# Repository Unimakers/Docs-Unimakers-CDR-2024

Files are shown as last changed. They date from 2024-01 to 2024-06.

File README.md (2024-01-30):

# Template-project

Template pour la création d'un repo type projet pour le MakerSpace. Doc gérée via le thème [Just-The-Docs](https://just-the-docs.com) en vanilla.

## Bienvenue sur Notre Projet

Ce repository est le cœur de notre projet. Ici, vous trouverez toutes les ressources nécessaires pour comprendre, utiliser et contribuer à notre projet.

### Contenu du Repository

- **Documentation :** Toutes les documentations techniques et guides d'utilisation sont disponibles dans le dossier `docs`. Voir le site de doc associé. 
- **project :** Toutes les sources de notre projet.

### Comment Utiliser ce Repository ?

- Pour commencer, consultez la documentation dans le dossier `docs`.
- Si vous souhaitez contribuer au projet, veuillez lire nos directives de contribution.

## Contribution

Nous accueillons et apprécions toute contribution. Si vous souhaitez contribuer, veuillez consulter notre guide de contribution pour connaître nos attentes et notre processus.

## Contact

Si vous avez des questions ou des suggestions, n'hésitez pas à nous contacter.

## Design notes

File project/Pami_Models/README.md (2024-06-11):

Voici le lien vers le fichier final du projet :

https://cad.onshape.com/documents/02834f8063c7122651a1e116/w/560aea271cad3373c1abc5b6/e/3381d3059c6bdee013f704c1

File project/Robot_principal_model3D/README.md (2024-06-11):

# Lien OnShape du robot principal

https://cad.onshape.com/documents/e7f1cd6065f4855bbf7ee889/w/294a25ebd50bad2a9f131b9e/e/20f33280a5619a7927049fd3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

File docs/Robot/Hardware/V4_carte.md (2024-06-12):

---
layout: technicals
grand_parent: Robot
parent: Hardware
nav_order: 4
title: V4 Carte
---

# Le temps est écoulé, le 4e candidat est retenu

<kicanvas-embed controls="full">
    <kicanvas-source src="./V4_carte_files/MainBoardV4.kicad_sch"></kicanvas-source>
    <kicanvas-source src="./V4_carte_files/Meca.kicad_sch"></kicanvas-source>
    <kicanvas-source src="./V4_carte_files/Power.kicad_sch"></kicanvas-source>
    <kicanvas-source src="./V4_carte_files/Servo.kicad_sch"></kicanvas-source>
    <kicanvas-source src="./V4_carte_files/Logic.kicad_sch"></kicanvas-source>
    <kicanvas-source src="./V4_carte_files/steppers.kicad_sch"></kicanvas-source>
    <kicanvas-source src="./V4_carte_files/MainBoardV4.kicad_pcb"></kicanvas-source>
</kicanvas-embed>

Voici la dernière carte à jour qui a participé à la coupe dans le robot. Cette carte nous a permis d'avoir tout ce dont nous avions besoin pour que le robot fonctionne correctement. Par rapport à la V3, cette carte a tous ses composants d'un seul côté du PCB, ce qui nous permettait de router tous les fils d'un côté du robot, minimisant les risques que les actionneurs s'emmêlent dans les fils.

Voici un schéma résumant les fonctionnalités de la carte !

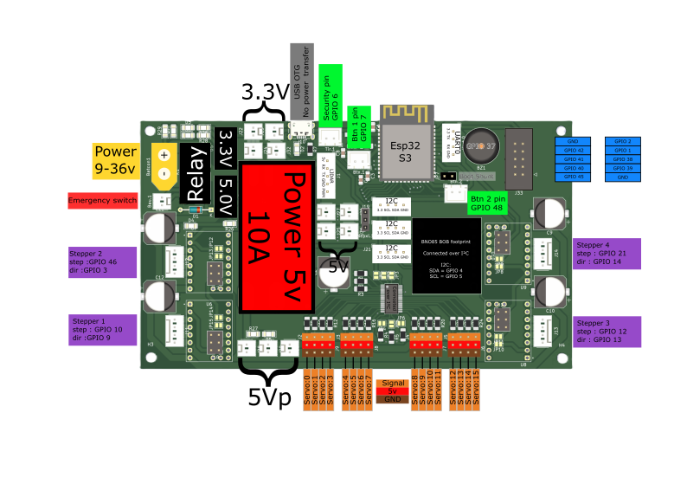
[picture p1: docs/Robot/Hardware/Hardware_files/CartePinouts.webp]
Pinout de la carte électronique


Quelques caractéristiques de cette carte :

| **Éléments** | **Détail** |
| --- | --- |
| Tension d'alimentation | Min : voir Traco puissance, Max : 36V |
| Type de microcontrôleur  | ESP32-S3-WROOM-1-8MB |
| Type de contrôleur Servo | PCA9685PW, connecté en I²C |
| Emplacements Servo | 16x, supportant jusqu'à 10A partagés |
| Type de driver | Par défaut : TMC2209, configurable en DRV8825 ou A4988 |
| Configuration drivers | TMC2209 : pas de configuration nécessaire, DRV8825/A4988 : souder les jumpers |
| Type de relais | Relay_SPST_TE_PCH-1xxx2M, ou à shunter en cas d'absence |
| Configuration relais | Choisir le relais en fonction de la tension utilisée. Sinon, shunter les connexions entre la COM et NO ! Ne pas utiliser le BAU sur carte si shunté ! |
| Type de gyroscope | BNO_085 en I²C |
| Tension de sortie 3,3V | Jusqu'à 2 ampères, partagés avec l'ESP32, les drivers et l'I²C |
| Tension de sortie 5V | Jusqu'à 2 ampères, partagés avec le LIDAR et Neopixel |
| Connecteurs I²C | 3,3V, partagés avec l'ESP32 |
| Connecteur Lidar | 5V, partagés avec Neopixel, UART 1, PWM |
| Connecteur Nappe | Compatible avec les cartes AREA |

> je laisse un peu de santé physique [ici](https://www.youtube.com/watch?v=dQw4w9WgXcQ) -Dylan

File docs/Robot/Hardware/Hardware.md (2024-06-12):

---
layout: technicals
parent: Robot
nav_order: 2
title: Hardware
has_children: true
---
## Sans éléments, on n'ira pas loin

Les robots comportent plusieurs systèmes de nature différente. Pour notre robot, nous avons identifié les systèmes suivants :

- Systèmes mécaniques
- Systèmes électroniques
- Systèmes lumineux

Chacun de ces systèmes joue un rôle distinct dans le fonctionnement du robot, mais ils ne fonctionnent pas indépendamment. Ils sont soigneusement interfacés pour que chaque composant contribue efficacement à l'ensemble du robot.

## Le mouvement, on y va de "pas en pas"

Pour le mouvement, nous avons opté pour des moteurs pas à pas Nema 17, couramment utilisés dans les imprimantes 3D et connus pour leur couple adéquat pour des systèmes légers.

<model-viewer disable-zoom src="./Hardware_files/Nema17.glb" ar ar-modes="webxr scene-viewer quick-look" camera-controls tone-mapping="commerce" poster="./Hardware_files/poster.webp" shadow-intensity="1"> </model-viewer>

Voici la [documentation](https://www.omc-stepperonline.com/fr/nema-17-bipolaire-45ncm-64oz-in-2a-42x42x40mm-4-fils-avec-1m-de-cable-et-connecteur-17hs16-2004s1) du Nema 17 utilisée.

<embed src="./Hardware_files/17HS16-2004S1.pdf" type="application/pdf" style="width: 100%; height: 100vh; border: none; display: block; margin: 0; padding: 0;"/>

Nous avons choisi ce modèle de moteur en utilisant le calculateur disponible sur le site du makerspace, en fonction du cahier des charges prévisionnel suivant :

[Calculateur en ligne](https://makerspace-amiens.fr/pages/calculateur-moteur-robot/){: .btn .btn-purple }

| Caractéristique | Valeur |
|---|---|
| Poids | 6 kg |
| Vitesse | 0,5 m/s|
| Accélération | 2 m/s² |
| Nombre de moteurs | 2 |
| Rayon roue motrice | 60 mm  |
| Tension d'alimentation  | 12 V |
| Efficacité | 65% |
| Temps de fonctionnement | 2 h |

Cependant, nous avons constaté que ces moteurs ne fournissaient pas le couple attendu en pratique, probablement en raison de la qualité des marques noname que nous avions. Cela nous a conduits à choisir un modèle supérieur, les Nema 23. Voici la [documentation](https://www.omc-stepperonline.com/fr/nema-23-bipolaire-1-8deg-0-9-nm-127-5oz-in-2a-3-6v-57x57x52mm-4-fils-23hs20-2004s).

<embed src="./Hardware_files/23HS20-2004S.pdf" type="application/pdf" width="100%" height="560px" />

Ces moteurs sont un peu plus encombrants que les Nema 17, mais ils permettent d'utiliser le robot en transmission directe (direct drive), c'est-à-dire que la roue est directement fixée sur l'arbre moteur.

<model-viewer src="./Hardware_files/NEMA23.gltf" ar ar-modes="webxr scene-viewer quick-look" camera-controls tone-mapping="commerce" poster="./Hardware_files/Nemaposter.webp" shadow-intensity="1" disable-zoom>
    <div class="progress-bar hide" slot="progress-bar">
        
    </div>
</model-viewer>

Un moteur pas à pas fonctionne en effectuant des rotations par pas. Un changement de polarité permet de passer d'une position à une autre. Dans notre cas, ce changement est géré par notre programme via un driver nommé TMC2209. La [documentation du TMC2209 ici](https://www.analog.com/en/products/TMC2209.html).

<embed src="./Hardware_files/TMC2209_datasheet_rev1.08.pdf" type="application/pdf" width="100%" height="600px" />

Pour les mouvements des actionneurs, nous avons principalement utilisé des servomoteurs. Ce sont des moteurs à courant continu (DC) qui intègrent un régulateur de position. En envoyant un signal PWM (pulse width modulation), en français MLI (modulation de largeur d'impulsion), nous pouvons commander le moteur à se positionner à un certain angle. 
Les références que nous avons utilisées sur le robot sont :
- FS 5115M [documentation ici](https://www.gotronic.fr/pj2-fs5115m-2553.pdf)
- Servo MG996R [documentation ici](./Hardware_files/mg996r.pdf)

<model-viewer src="./Hardware_files/MG996RServo.glb" ar ar-modes="webxr scene-viewer quick-look" camera-controls tone-mapping="commerce" poster="./Hardware_files/posterServo.webp" shadow-intensity="1">
    <div class="progress-bar hide" slot="progress-bar">
        
    </div>
</model-viewer>

## Une source d'énergie, et ce n'est pas de la vapeur !

Comme source d'énergie, nous avons opté pour des batteries déjà disponibles dans l'association, notamment les Parkside A3.

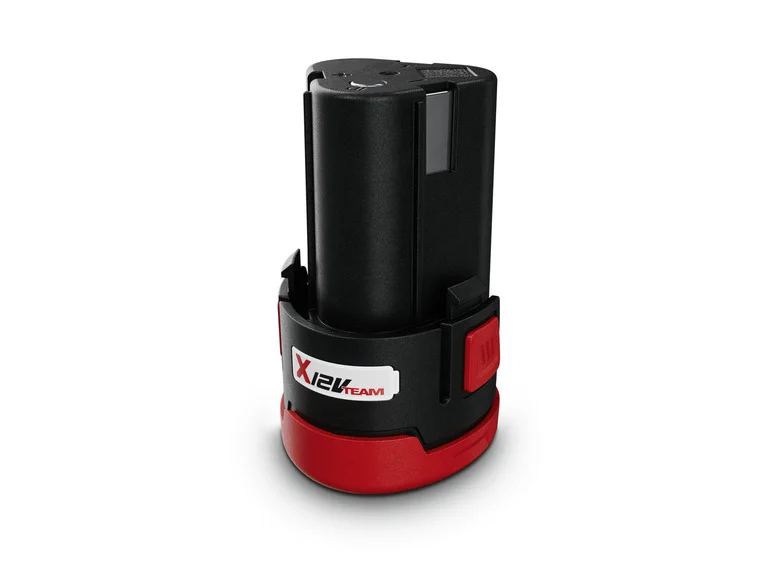
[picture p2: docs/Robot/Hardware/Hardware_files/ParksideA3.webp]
Batterie Parkside


Deux de ces batteries sont en série dans le robot pour augmenter la tension vers 24V, ce qui permet de suivre les courbes de couple proposées par les Nema 23.

Pour l'autonomie de ces batteries, nous sommes aux alentours de 1h30 voire 2h.

Nous avons pensée a prendre des parkside B3, mais ceux si etaient trop encombrant, ainsi qu'une tension non adapté au besoins

## Des yeux, il en faut pour ne pas etre aveugle

Nous avons opté pour un LIDAR RP A2 de slamtec, ce LIDAR est a déja disponible dans l'association

Voici la page du lidar pour plus d'information [Page du lidar](https://www.slamtec.ai/product/slamtec-rplidar-a2/)

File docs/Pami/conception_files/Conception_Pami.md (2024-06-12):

---
layout: technicals
parent: PAMI
nav_order: 1
title: Conception
has_children: true
---

# Conception & Modélisation des PAMI

## Introduction

Les **PAMI** (Petit Actionneur Mobile Indépendant) sont de petits robots soumis à plusieurs règles de conception, dont les contraintes volumétriques sont les plus importantes. En effet, il n'y a pas de nombre limite de PAMI présents sur la table de jeu, cependant, l'ensemble des PAMI doit tenir dans une zone de 150mm x 450mm et 150mm de hauteur. Ils ont également une limite de poids fixée à 1,5kg dans le règlement final. Cependant, le premier règlement (béta) limitait le poids des PAMI à 1kg. Afin de respecter les contraintes volumétriques, la conception de base repose sur un volume carré ou rectangulaire dans lequel nous intégrons nos composants.

### PoC (Proof of Concept)

Avant toute conception des PAMI, il était crucial de choisir le moteur adéquat pour concevoir le corps du robot. Pour cela, j'ai utilisé un outil de calcul de couple. Avec ces informations en main, j'ai trouvé les moteurs steppers nécessaires : des [Nema 14 rond](https://www.omc-stepperonline.com/fr/rond-nema-14-bipolaire-0-9deg-9-ncm-12-75-oz-in-1-0a-36-5x17-5mm-4-fils-14hr07-1004vrn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) ou pancake.

Suite à ce choix, j'ai rapidement réalisé une petite pièce pour valider les moteurs et commencer à imaginer les volumes du PAMI.

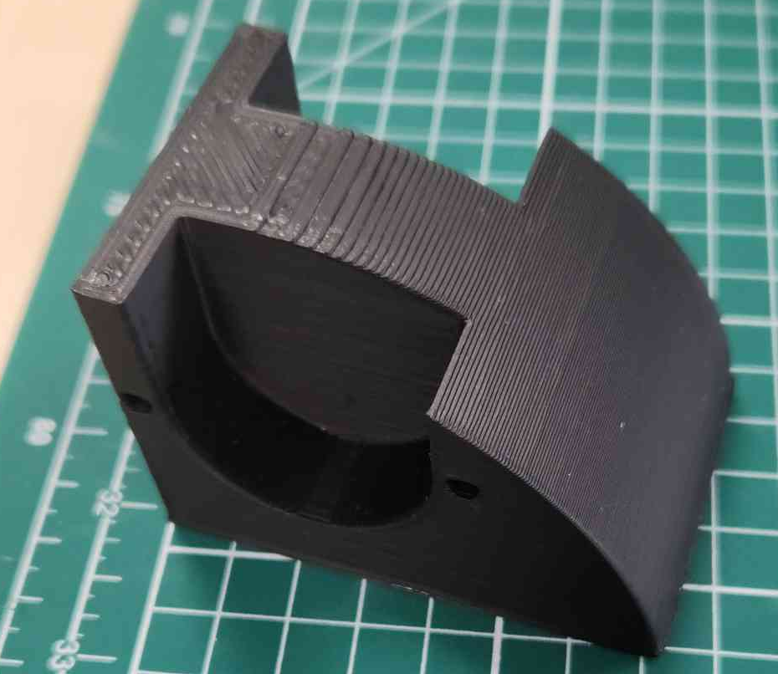
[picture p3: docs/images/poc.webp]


La première version de la conception des PAMI visait à créer un maximum de PAMI dans une zone la plus compacte possible. Après plusieurs heures de conception, j'ai obtenu un premier modèle 3D.

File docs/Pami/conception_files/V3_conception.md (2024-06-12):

---
layout: technicals
grand_parent: PAMI
parent: Conception
nav_order: 3
title: Version Final
---

<style>
	.video-container {
		position: relative;
		padding-bottom: 56.25%; /* Ratio 16:9 */
		height: 0;
		overflow: hidden;
		max-width: 100%;
		background: #000;
	}

	.video-container video {
		position: absolute;
		top: 0;
		left: 0;
		width: 100%;
		height: 100%;
	}
    .belleimage:hover {
        transform: scale(1.35);
    }
</style>

# Conception & Modélisation des PAMI

## Version Finale

<model-viewer src="./3d_files/pami-vfinal.glb" ar ar-modes="webxr scene-viewer quick-look" camera-controls tone-mapping="neutral" poster="./3d_files/v3.webp" shadow-intensity="1" style="display: block; margin-left: auto; margin-right: auto; height: 600px; width: 600px;">
    <div class="progress-bar hide" slot="progress-bar">
        
    </div>
</model-viewer>

La version 3, ou version finale, est une continuité et une amélioration du concept de la V2. Le changement principal est le remplacement des steppers par une nouvelle référence. La grande modification est le changement complet de l'emplacement des composants, passant d'un agencement circulaire à un agencement carré.

Avec le body réadapté et la carte finale réalisée, nous avons pu continuer notre conception. Sur la plaque supérieure, il fallait intégrer plusieurs emplacements pour les différents composants qui s'y fixent :

- Un emplacement pour visser le bouton d'arrêt d'urgence
- Un support pour le capteur Reed
- Un emplacement pour le switch de stratégie (bleu ou jaune)
- Un support et une attache pour le capteur ultrason
- Un emplacement pour le servo-moteur destiné à toucher les plantes

<div style="display: flex; justify-content: space-around;">
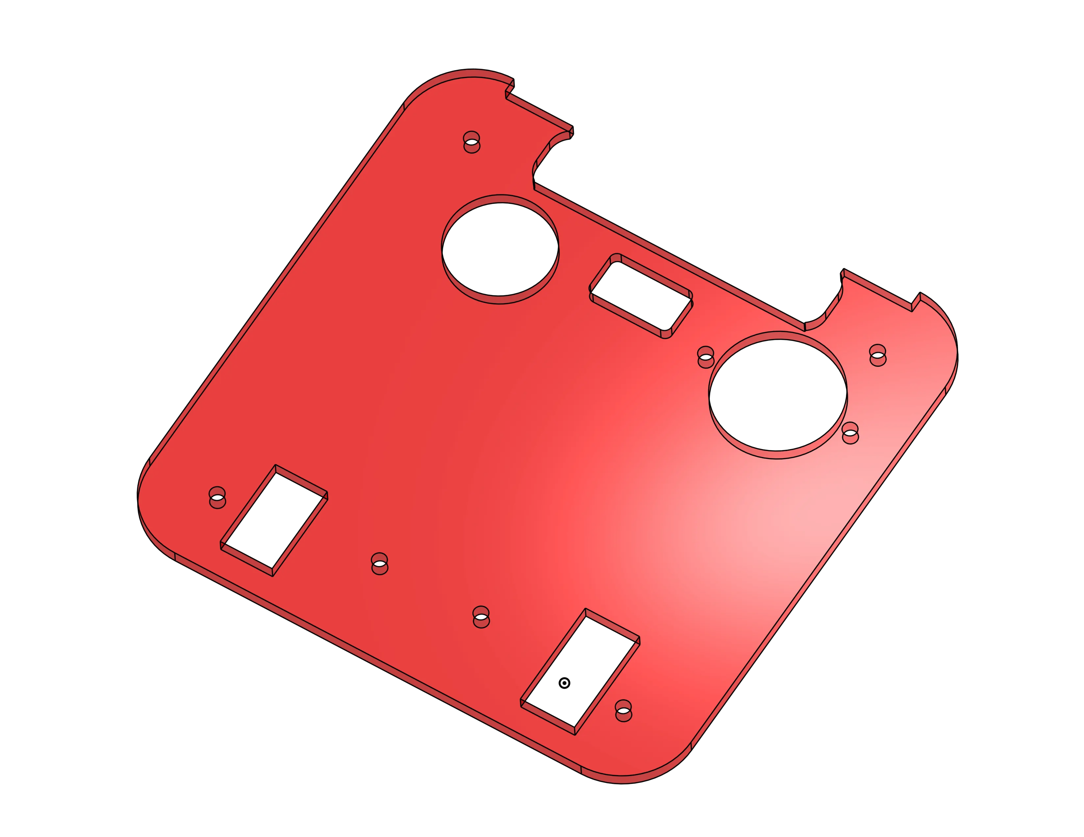
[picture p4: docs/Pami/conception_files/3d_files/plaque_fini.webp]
    
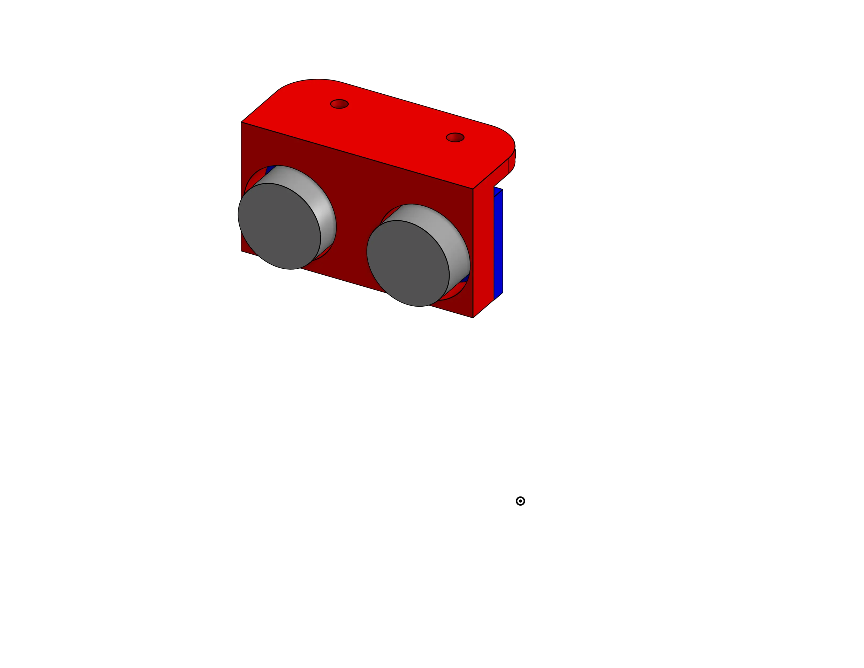
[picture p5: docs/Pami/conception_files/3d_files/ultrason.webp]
    
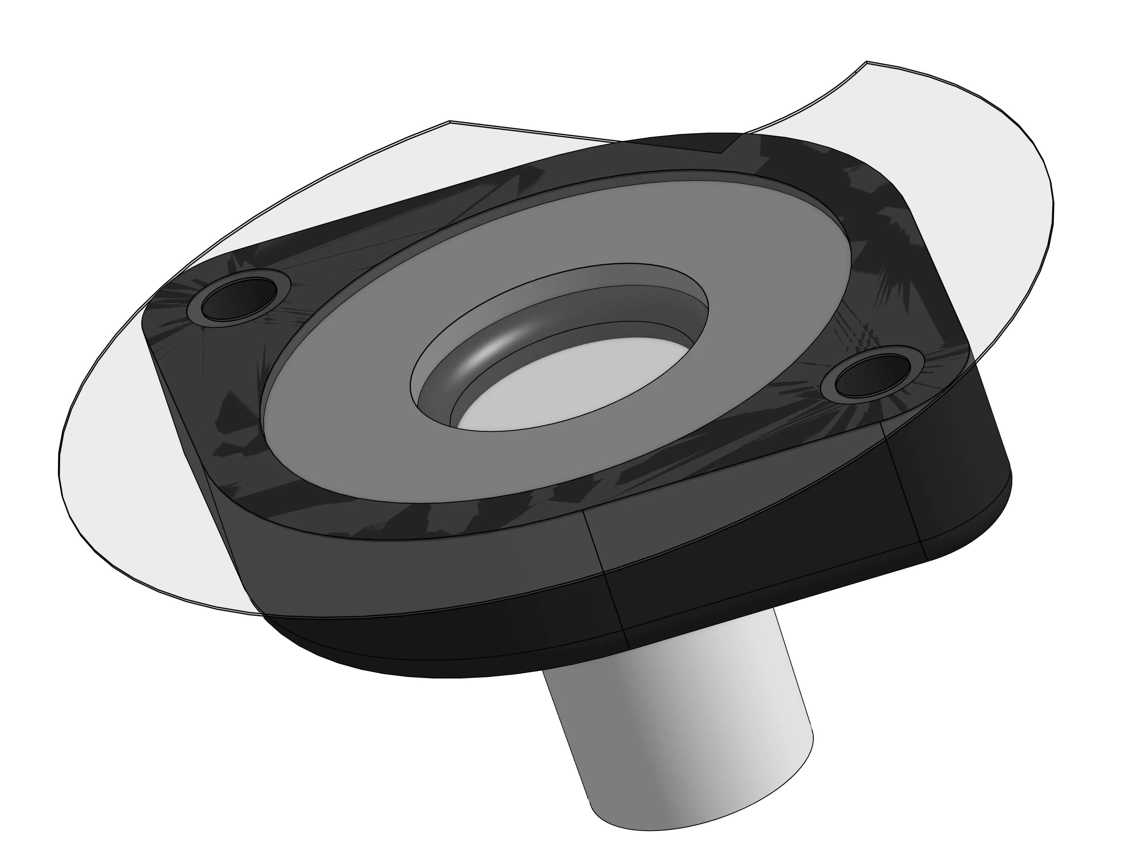
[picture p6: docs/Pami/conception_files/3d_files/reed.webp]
    
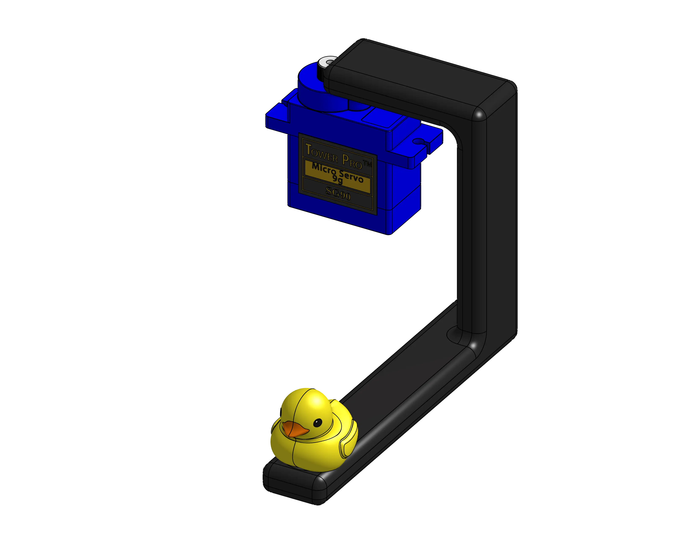
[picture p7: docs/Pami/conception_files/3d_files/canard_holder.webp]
    
</div>

Une fois tous les prototypes validés, nous sommes passés au montage final des PAMI 2 et 3. En voici le résultat.

<div class="video-container">
    <video muted autoplay loop>
        <source src="./3d_files/pami-montage.webm" type="video/webm">
    </video>
</div>

## Conclusion

Le développement du PAMI a été un projet évolutif marqué par de multiples améliorations et différents échecs. De la version initiale à la version finale, chaque étape a permis de résoudre des problèmes et d'optimiser la conception pour atteindre progressivement les objectifs fixés en termes de fonctionnalité et de performance.

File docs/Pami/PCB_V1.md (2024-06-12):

---
layout: default
grand_parent: PAMI
parent: Électronique
nav_order: 1
title: PCB_V1
---

## Spécificités de la version 1 :

Étant ma toute première réalisation de PCB, j'ai opté pour un design visuellement intuitif (voir PCB) comprenant uniquement les composants les plus cruciaux, en essayant de rester sur une carte au minimum compactée en guise de carte test. Ainsi, dans le schéma, vous trouverez l'élaboration des composants phares.
L'objectif dans la réalisation de ce shéma est de mettre en liens les differents composants avec les dipoles dont ils ont besoin pour leur bon fonctionnement.

### Schéma

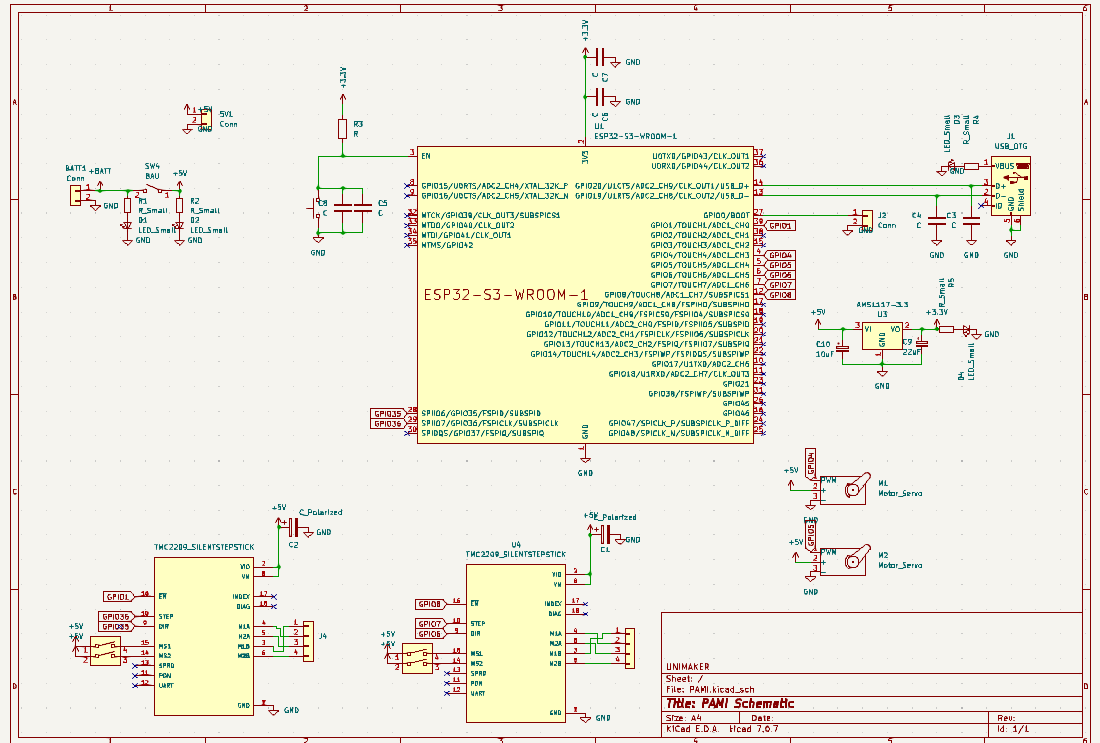
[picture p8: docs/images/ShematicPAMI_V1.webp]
Illustration schématique


- L'ESP32-S3-VROOM se met en lien avec des condensateurs pour augmenter la stabilité de son alimentation et limiter les bruits numériques
- Les pins de transport de données du port USB_OTG sont égalements dotés de capacitées pour des raisons de filtrage numérique ainsi que un set résistance/diode connecté à la source d'alimentation du module afin de vérifier son bon fonctionnement. 
- Des switch sont lié aux pins de step des contrôleurs moteurs TMC2209 SILENTSTEPSTICK afin de sélectionner manuellement notre configuration, il a également fallut déporter les pins des bobines magnétiques afin de les ordonnées en vue de leurs branchement.
- Le régulateur de tension Traco TSR_2-2433 est mis ene lien avec des condensateurs de sorte a augmenter la stabilité de la tension, un set resistance/diodes est également ajouté pour son vérifier son bon fonctionnement.
- **Bouton d'activation du microcontrôleur**
- **Interrupteur d'arrêt d'urgence**
- **LEDs de vérification de l'état des circuits**

### PCB

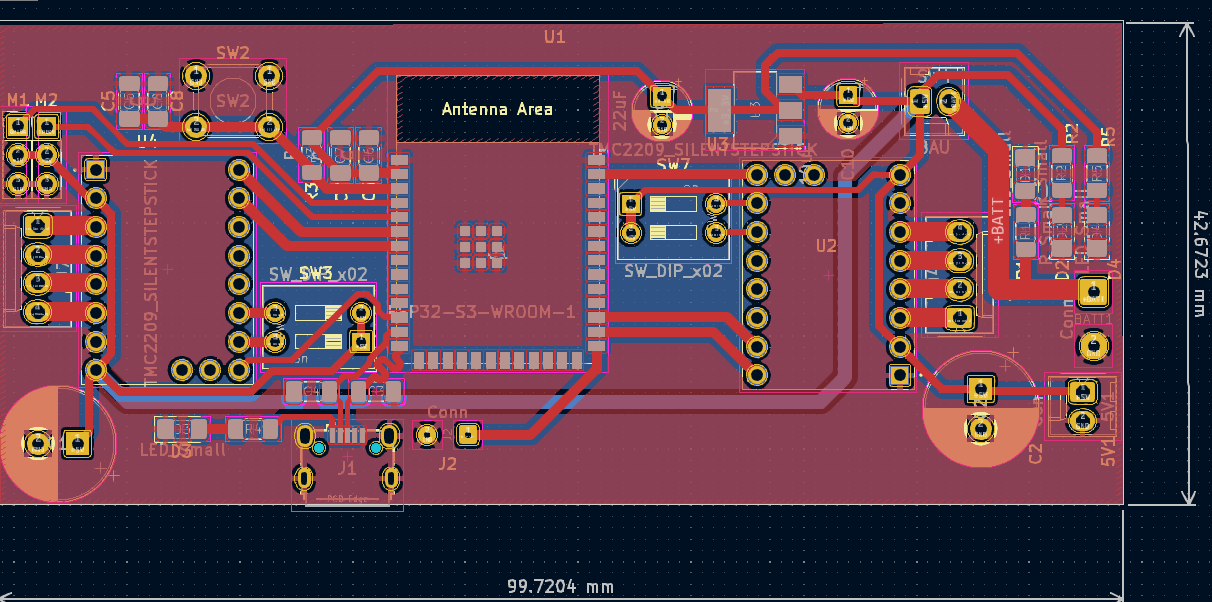
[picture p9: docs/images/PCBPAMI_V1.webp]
Image PCB


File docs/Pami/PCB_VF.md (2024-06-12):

---
layout: default
grand_parent: PAMI
parent: Électronique
nav_order: 2
title: PCB_VF
---

## Ajouts de fonctionnalités

- **Buzzer_Beeper** : Feedback sonore des actions du PAMI.
- **Screen** : Feedback visuel de l'état du PAMI.
- **Interrupteur de changement de stratégie**.
- **Actionneur de LED néopixel**.

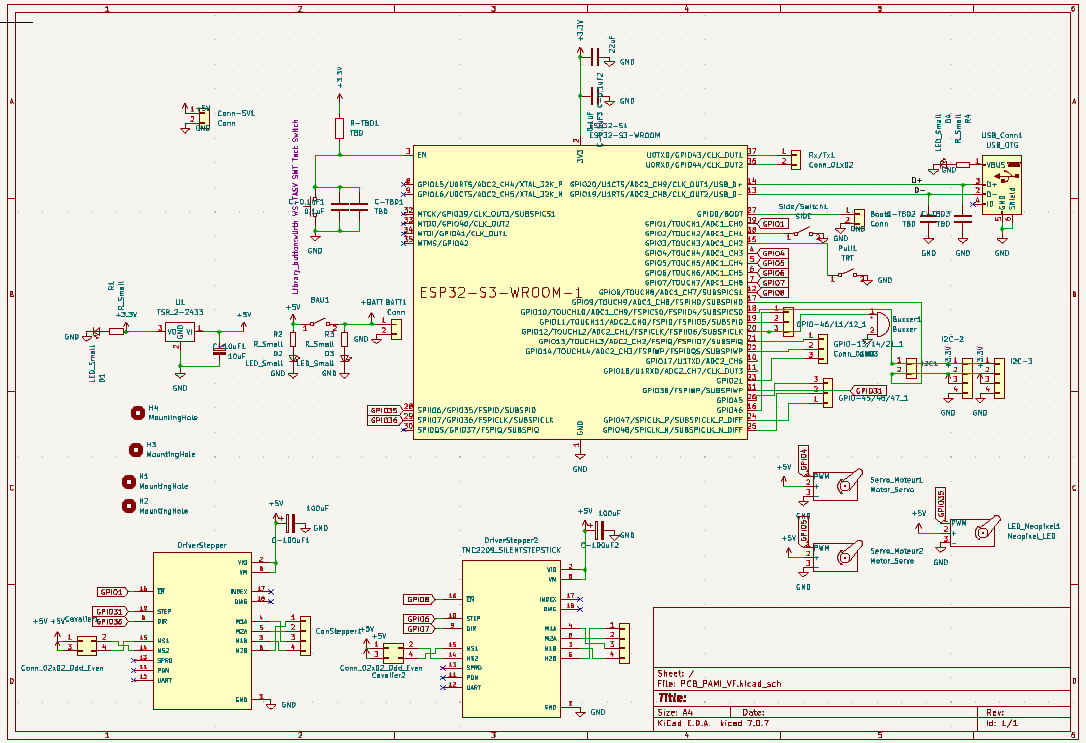
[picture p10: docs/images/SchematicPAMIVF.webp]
Schéma


## Adaptation du design

- Passage à un format 80x80 mm.
- Ajout de trous pour le passage de câbles.
- Intégration d'une légende.

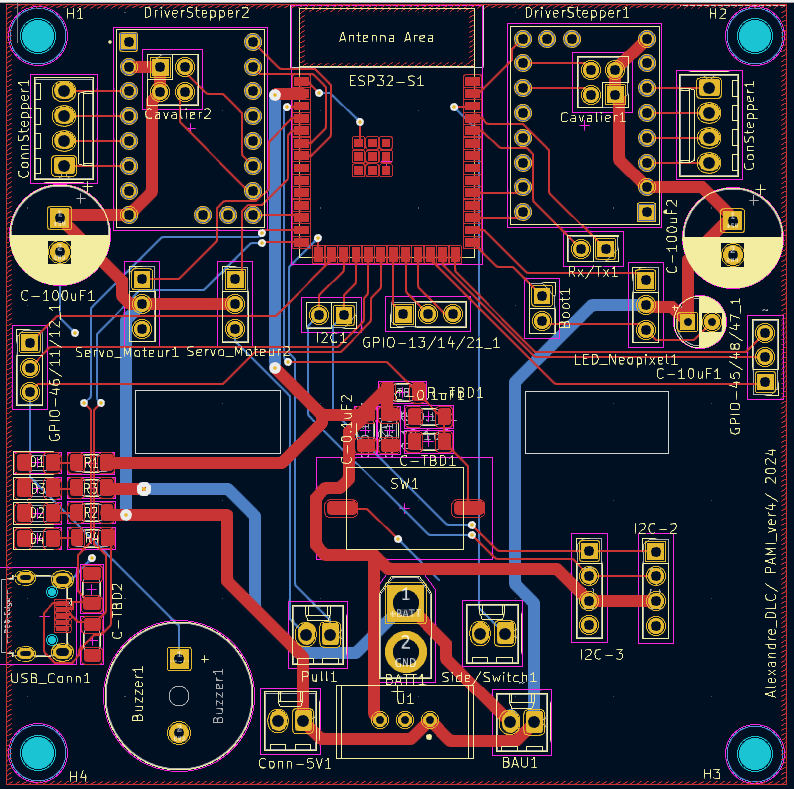
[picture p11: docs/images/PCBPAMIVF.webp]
PCB


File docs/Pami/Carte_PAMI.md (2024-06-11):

---
layout: default
parent: PAMI
nav_order: 2
title: Électronique
has_children: true
---

## Contexte

La carte du PAMI doit permettre à un châssis sur roues de se déplacer vers son objectif (plantes) sur un terrain de 2m x 3m pendant 10 secondes, en respectant les mesures de sécurité.

## Cahier des charges

- **Contrôle de trajectoire :**
  - Atteindre les plantes rapidement et efficacement.

- **Arrêt d'urgence :**
  - Avoir un bouton d'arrêt d'urgence à disposition.

- **Détection d'obstacle :**
  - Être capable de s'arrêter automatiquement à l'approche d'un obstacle.

## Contraintes

- **Dimensions :** 80mm x 80mm
- **Quantité de couches de circuits électriques possibles :** 2 couches
- **Points de fixation :** 4 trous de 3mm de diamètre

## Conception

### Choix des composants

- **ESP32-S3-VROOM :** Microcontrôleur standardisé suffisamment récent.
- **Port USB_OTG**
- **TMC2209 SILENTSTEPSTICK :** Drivers de moteur pas à pas à disposition du club.
- **Traco TSR_2-2433 :** Régulateur abaisseur de tension 5V/3.3V à disposition du club.
- **Interrupteurs :**
  - Interruption d'urgence de l'alimentation.
  - Activation du microcontrôleur.
  - Changement de stratégie.
- **Buzzer/Beeper :** Feedback sonore des actions du PAMI.
- **Écran :** Feedback visuel de l'état du PAMI.
- **LEDs de vérification :** Feedback électrique de l'état des circuits.

### Choix de l'alimentation 5V/3.3V

- **5V :** Utilisé pour les moteurs pas à pas et les servomoteurs.
- **3.3V :** Utilisé pour le transfert de données au sein de la carte.

### Détermination du design

- **Antenne :** Besoin que l'antenne ne soit pas obstruée.
- **Gestion des câbles :** Besoin de passages pour organiser les câbles.

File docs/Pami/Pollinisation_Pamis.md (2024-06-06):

---
layout: default
grand_parent: PAMI
parent: Programmation
nav_order: 3
title: Pollinisation
---

# Pollinisation

## Déploiement du bras

Pour pouvoir polliniser les plantes, le PAMI est équipé d'un bras lié à un servomoteur. Ce bras est déployé à la suite du déplacement du PAMI pour toucher la plante. Le servomoteur utilisé est le [SG90](https://boutique.semageek.com/fr/104-micro-servo-tower-pro-sg90-3007447379574.html), contrôlable sur une plage d'angle de 0° à 180°. Ce choix est justifié par son faible coût et l'utilisation que nous en faisons.

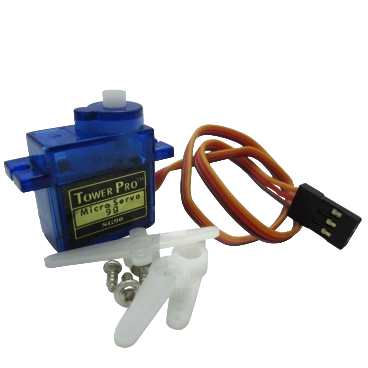
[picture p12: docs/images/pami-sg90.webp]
Servomoteur SG90


## Stratégie

Lorsque le PAMI a terminé ses déplacements, le servomoteur passe d'un angle de 0° à 45° afin d'étendre le bras pour toucher la ou les plantes. Nous disions dans la partie [obstacles](./Obstacles_Pamis.html) qu'il n'était pas possible pour nous de différencier une plante d'un robot adverse. Ainsi, si le robot ne termine pas son déplacement car un obstacle l'a arrêté, le bras se déploie tout de même dans l'éventualité qu'une plante fasse obstacle.

## En douceur

Si le PAMI renverse une plante, nous n'obtenons pas de points. Donner l'ordre au servomoteur de passer de 0° à 45° directement provoque un déplacement "violent", pouvant faire basculer la plante. Une solution a été d'incrémenter petit à petit l'angle de rotation pour linéariser le déplacement. À chaque incrément, nous faisons une pause de 5 ms.

### Extrait du code

```c
void sweepJardiniere() {
	for (int i = 1; i <= 45; i++) {
		sg90.write(i);
		delay(5);
	}
}
```

## Axes d'amélioration

Le bras effectuait le contact avec la plante une fois sur deux. Cela s'explique par l'emplacement des plantes variant d'un match à l'autre selon comment le robot principal les plaçait.

Revoir la façon dont nous utilisons le servomoteur pour déployer un bras aiderait à avoir un meilleur taux de contact.

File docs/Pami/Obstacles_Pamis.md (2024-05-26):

---
layout: default
grand_parent: PAMI
parent: Programmation
nav_order: 2
title: Obstacles
---

# Obstacles

## Choix du capteur

Afin de donner la possibilité au PAMI de s'arrêter face à un obstacle et ainsi éviter la collision, nous devons choisir un capteur capable de mesurer avec une précision correcte la distance entre le PAMI et l'obstacle. Notre choix s'est naturellement porté sur le [HC-SR04](https://www.gotronic.fr/art-module-de-detection-us-hc-sr04-20912.htm), un capteur ultrasonique utilisé pour mesurer des distances en émettant des ondes sonores et en calculant le temps que met l'écho à revenir. C'est une solution peu onéreuse et fiable à implémenter.

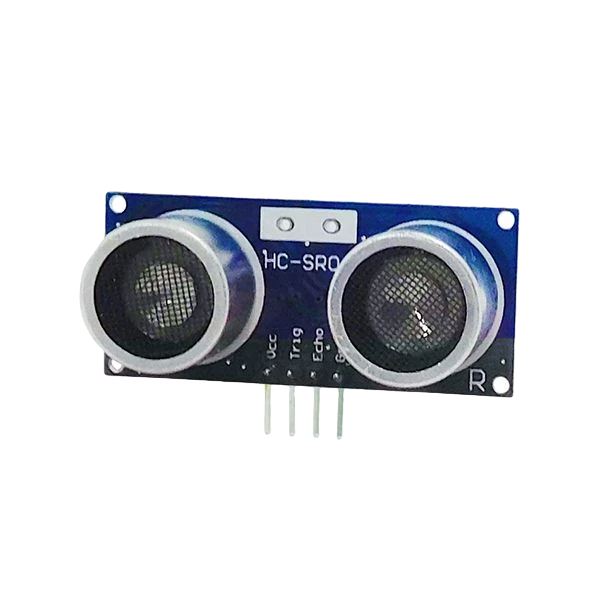
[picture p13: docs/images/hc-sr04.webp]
Capteur ultrasonique HC-SR04


{: .note}
Le capteur ultrasonique applique la formule `distance = (temps * vitesse_son) / 2`. La vitesse du son dans l'air est de 340 mètres par seconde.

## Lecture des valeurs du capteur

### Identification de problèmes

En testant le capteur, nous nous sommes vite rendus compte que des valeurs parasites étaient retournées. Le PAMI s'arrête seulement si la distance retournée est inférieure ou égale à 31 cm. Le fait d'avoir des valeurs fausses rendait ses déplacements erratiques qui, par la même occasion, sautaient des pas sur les steppers.
Également, le capteur ne peut faire la différence entre une plante ou un robot. De ce fait, le PAMI s'arrête face à n'importe quel obstacle.

### Solution logicielle

Après un certain moment de réflexion, nous avons essayé d'implémenter une moyenne mobile des valeurs afin de filtrer les potentiels parasites. La tâche de lecture du capteur est quant à elle déportée sur le cœur n°2 afin de fluidifier l'exécution du code. Voici à quoi ressemble la fonction de mesure :

1. La fonction soustrait l'ancienne mesure de la somme totale des lectures.
2. Elle lit la nouvelle distance mesurée par le capteur et l'ajoute à la somme totale.
3. Elle met à jour l'index pour garder une trace de la position dans le tableau des lectures.
4. Elle calcule la distance moyenne en divisant la somme totale par le nombre de mesures (dans notre cas, 5).

Nous surveillons en continu la proximité d'obstacles en moyennant sur 5 valeurs et obtenons ainsi une unique valeur filtrée. La solution fonctionnant assez bien pour nous, nous l'avons adoptée.

#### Extrait du code

```c
int readings[SONAR_ITERATIONS], sonar_index = 0, total = 0, average;

for (;;) { // loop cœur n°2
	total -= readings[sonar_index];
	readings[sonar_index] = sonar.read();
	total += readings[sonar_index];

	sonar_index = (sonar_index + 1) % SONAR_ITERATIONS;

	average = total / SONAR_ITERATIONS;

	if (average <= 31) {
		obstacle = true;
		tone(BUZZER, 444);
	} else {
		obstacle = false;
	}
}
```

## Intégration de la détection

### Dans les déplacements

Maintenant que la valeur de notre capteur est utilisable, nous devons interpréter la distance des obstacles. Dans notre cas, nous avons juger qu'une tolérance de 32 cm et plus était acceptable. Le PAMI réagit assez rapidement et cela lui permet de s'arrêter en premier dans le cas d'un choc frontal avec un autre robot. Ainsi, quand le capteur retourne une valeur inférieure ou égale à 31 cm, il signale la présence d'un obstacle en passant la variable booléenne globale `obstacle` à l'état **VRAI**. Dans le cas contraire, cette variable est à l'état **FAUX**. De cette façon, nous savons si les [steppers](./Steppers_Pamis.html) ont le droit d'exécuter leurs pas en consultant tout simplement l'état de la variable.

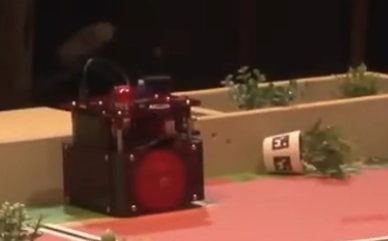
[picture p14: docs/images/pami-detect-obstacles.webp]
Un PAMI, détectant un obstacle, ne bouge plus


*Hélas, comme nous ne pouvions pas faire la différence entre une plante ou un robot, le PAMI sur l'image ci-dessus s'arrête face à une plante.*

### En retour sonore

Au moment où la variable `obstacle` est à l'état **VRAI**, nous envoyons un signal à notre buzzer piézoélectrique afin d'avoir un retour sonore de la détection d'obstacles. Tant que l'obstacle est présent, le buzzer émet une note aiguë. Cela a pour avantage une visualisation simplifiée de la lecture du capteur et de l'exécution du code associé.

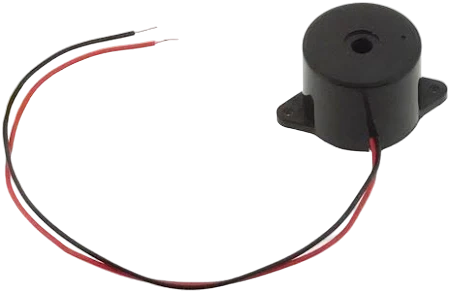
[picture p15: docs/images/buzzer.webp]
Buzzer piézoélectrique


## Axes d'amélioration

En l'état actuel, nous sommes satisfaits de l'utilisation du capteur ultrasonique. Lors de son utilisation, nous n'avons jamais rencontré de soucis, il était rapide et très simple à implémenter. Le choix de ce capteur était donc judicieux. Mais après avoir pu mettre le PAMI en pratique, quelques axes d'amélioration nous sont venus à l'esprit :

1. Le choix d'un capteur ultrasonique fournissant déjà un filtrage parasite sur la partie hardware peut être plus fiable à utiliser. Cela nous évite de mettre en place une moyenne mobile qui ralentit la détection d'obstacle.
2. Avoir au moins deux capteurs ultrasoniques positionnés à différentes hauteurs pourrait aider à discerner les obstacles négligeables des obstacles critiques (voir l'image du PAMI qui s'arrête face à une plante).

Étudier ces deux points pourrait nous aider à fiabiliser davantage le système de détection d'obstacles.

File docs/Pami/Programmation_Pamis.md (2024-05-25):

---
layout: default
parent: PAMI
nav_order: 3
title: Programmation
has_children: true
---

# Programmation du microcontrôleur ESP32

## Objectifs

La programmation du microcontrôleur réalise ainsi ces actions :
- Pollinisation des jardinières
- Détection de potentielles collisions
- Synchronisation avec le robot principal

## Logique fonctionnelle

La logique fonctionnelle du PAMI repose sur une séquence d'actions précises pour garantir le bon déroulement de ses tâches durant le match :

1. **Initialisation :** Après 90 secondes de match, l'ESP32 active les steppers ainsi que le servomoteur, et lance la série d'instructions pour la stratégie.
2. **Navigation :** Le PAMI quitte sa zone de départ et se dirige vers sa zone de pollinisation attribuée dans son code. Il s'assure d'éviter les obstacles à l'aide de son capteur ultrason.
3. **Pollinisation :** Une fois arrivé à destination, le PAMI établit le contact avec la plante et reste ainsi jusqu'à la fin du match.
4. **Désactivation :** Après un peu moins de 10 secondes passées, l'ESP32 désactive les steppers ainsi que le servomoteur. Ainsi, nous empêchons une potentielle disqualification due à une erreur de déplacement du PAMI.

Algorigramme PAMI

Cela constitue donc la base programmable pour notre robot que l'on va implémenter.

## Timers hardware

Les opérations d’initialisation et de désactivation du PAMI sont possibles grâce à l’utilisation de timers hardware présents sur l’ESP32. Ils permettent de mesurer le temps écoulé avec une grande précision, tout en étant indépendants du CPU. Ainsi, lors de la mise sous tension de la carte électronique, le microcontrôleur traite les instructions demandées dans le code au démarrage. Il définit ensuite un timer comptant jusqu’à 99 secondes. Au déclenchement de la tirette, le timer démarre. Après avoir compté 90,5 secondes, il lance la stratégie du PAMI. Lorsque les 99 secondes sont atteintes, le timer expire et force l’exécution d’une fonction désactivant les steppers et le servomoteur. À ce moment-là, la carte a terminé l’exécution du code.

## Outils de développement utilisés

Pour bien appréhender la programmation de l'[ESP32-S3](https://www.espressif.com/en/products/socs/esp32-s3), il est essentiel de mettre en place l'environnement de développement qui servira tout le long du projet. Cette section détaille donc les outils et les bibliothèques nécessaires pour coder, tester et déployer notre PAMI.

### Outils logiciels

- **[Visual Studio Code](https://code.visualstudio.com/) :** Un riche éditeur de texte performant où nous venons greffer des extensions afin d'obtenir l'IDE qui nous correspond.
- **[PlatformIO](https://platformio.org/) :** Une plateforme de développement, utilisée pour notre ESP32, offrant une gestion simplifiée des bibliothèques et des outils de compilation. Cela vient sous la forme d'une extension ajoutée à VSCode.

### Bibliothèques

- **[AccelStepper](https://github.com/waspinator/AccelStepper) :** Contrôle des moteurs pas à pas avec des fonctionnalités avancées comme l'accélération et la décélération. Nous l'utilisons pour la partie [steppers](./Steppers_Pamis.html).
- **[Ultrasonic](https://github.com/ErickSimoes/Ultrasonic) :** Interfaçage et contrôle des capteurs à ultrasons afin de mesurer des distances avec précision. Nous l'utilisons pour la partie [obstacles](./Obstacles_Pamis.html).
- **[ESP32Servo](https://github.com/jkb-git/ESP32Servo) :** Contrôle des servomoteurs en utilisant les broches PWM de l'ESP32. Nous l'utilisons pour la partie [pollinisation](./Pollinisation_Pamis.html).

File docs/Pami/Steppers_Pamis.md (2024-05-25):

---
layout: default
grand_parent: PAMI
parent: Programmation
nav_order: 1
title: Steppers
---

<style>
	.video-container {
		position: relative;
		padding-bottom: 56.25%; /* Ratio 16:9 */
		height: 0;
		overflow: hidden;
		max-width: 100%;
		background: #000;
	}

	.video-container video {
		position: absolute;
		top: 0;
		left: 0;
		width: 100%;
		height: 100%;
	}
</style>

# Steppers

## Déplacements

Les déplacements du PAMI s'effectuent à l'aide des deux steppers présents. La librairie AccelStepper nous permet de les piloter simplement. Lors du développement du code de déplacement, deux choix s'offraient à nous : utiliser les coordonnées relatives ou absolues. Nous avons d'abord décidé introduire le déplacement en relatif avant de tenter l'implémentation en absolu.

{: .note}
Le déplacement en coordonnées absolues d'un robot avec des steppers se réfère à lui donner une position précise dans l'espace global défini, tandis que le déplacement en coordonnées relatives indique que le robot se déplace d'une certaine distance par rapport à sa position actuelle.

## Liaison des deux steppers

Afin de faciliter l'écriture du code et la manipulation des deux steppers, nous avons utilisé la librairie [Motion](https://github.com/Unimakers/CDR-2024-FIRMWARE/tree/main/CDR2024%20BASE/lib/Motion) d'Unimakers, offrant une simplification accrue du pilotage. Celle-ci permet entre autre le déplacement en arc de cercle, ainsi que la liaison des deux steppers sous la forme d'un objet !

### Exemple de déplacement

Supposons que le PAMI doive avancer de 100 mm, tourner de 45° à gauche pour finir par avancer de 1000 mm. Nous pouvons passer la distance en mm dans la fonction car nous la multiplions par la constante `STEP_PER_MM` pour avoir la valeur en pas. Le code typique serait le suivant :

```c
void moveExample() {
	RobotSteppers.move_line(100 * STEP_PER_MM);
	while (!RobotSteppers.target_reached()) { RobotSteppers.run(); }

	RobotSteppers.turn(45);
	while (!RobotSteppers.target_reached()) { RobotSteppers.run(); }

	RobotSteppers.move_line(1000 * STEP_PER_MM);
	while (!RobotSteppers.target_reached()) {
		if (!obstacle) RobotSteppers.run();
	}
}
```

Dans l'exemple ci-dessus, nous donnons l'ordre aux steppers d'avancer en ligne droite de `100 * STEP_PER_MM` pas. Ensuite, nous exécutons ces pas tant que les steppers n'ont pas atteint leur position finale. C'est vérifiable en appelant la fonction `target_reached()` qui retourne **VRAI** ou **FAUX** selon si les pas restants sont différents de zéro. Une petite subtilité est présente sur la dernière partie : nous vérifions la présence d'obstacle. En effet, il y a plus de chance de rencontrer un obstacle sur un déplacement d'un mètre, nous devons donc être sûrs de l'arrêt de l'avancement dans le cas où un obstacle est présent face au PAMI. Pour comprendre comment cette variable booléenne `obstacle` est définie, vous pouvez lire la partie [obstacles](./Obstacles_Pamis.html). Lorsqu'un obstacle est présent, les pas ne sont plus exécutés. Le PAMI ne fait ainsi plus rien tant qu'un obstacle est présent.

### Exemple lors d'un match

<div class="video-container"><video muted autoplay loop><source src="../images/pami-move.webm" type="video/webm" /></video></div>

*La vidéo ci-dessus illustre bien la façon dont se déplacent les PAMI et comment la détection d'obstacle est implémentée.*

## Axes d'amélioration

En l'état actuel, nous sommes mitigés quant à l'utilisation des steppers. Lors de leur utilisation, il pouvait nous arriver de sauter des pas lors de la détection d'obstacle car l'arrêt des moteurs était brutal. Cela s'explique par la façon dont nous les avons utilisés : 

- La fonction `run()` d'AccelStepper fournit d'origine un mouvement fluide sur les steppers.
- Nous interrompions l'exécution de cette fonction quand un obstacle était présent.
- Quand le PAMI se trouvait à une certaine vitesse, interrompre son déplacement tentait de faire passer les steppers de la vitesse actuelle à une vitesse nulle.
- Les steppers, ne pouvant réaliser une telle chose, devenaient instables et sautaient des pas.
- Le déplacement (en coordonnées relatives) se retrouvait donc faussé.

Après avoir constaté cela en pratique, quelques axes d'amélioration nous sont venus à l'esprit :

1. Passer à des coordonnées absolues serait bien mieux pour pouvoir déplacer le PAMI à un endroit exact (POI).
2. Avoir une fonction d'arrêt adaptée nous éviterait de sauter des pas et permettrait un ralentissement en douceur.
3. Intégrer des encodeurs nous permettrait de corriger les déplacements dans le cas où les steppers sauteraient des pas.

Étudier ces trois points pourrait nous aider à fiabiliser davantage le système de déplacement du PAMI.

{: .note}
Un système de *Point Of Interest* (POI) permet de définir des points spécifiques que le robot doit atteindre ou surveiller, facilitant la navigation et les déplacements précis dans un environnement donné.

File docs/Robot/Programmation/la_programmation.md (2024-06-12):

---
layout: default
parent: Robot
nav_order: 3
title: La Programmation
---

# La Programmation

La programmation du robot s'est faite sous PlatformIO, une extension de VSCode qui permet de faire de la programmation embarquée. Cette extension offre plus de liberté que l'IDE Arduino, en profitant notamment du système de visualisation d'arborescence de VSCode.

## Intialisation

Le démarrage du robot se passe comme suit :

1. Initialisation du port série.
2. Initialisation du protocole LIDAR.
3. Initialisation du protocole I²C.
4. Initialisation des pinces.
5. Initialisation des modes de fonctionnement des GPIOs.
6. Mise à zéro des différentes variables de position.
7. Attente de la pose de la tirette et choix de la zone de travail.
8. Attente de l'enlèvement de la tirette.
9. Démarrage.

# déroulée après départ 

le code étant de consequent, nous allons proceder avec une diagramme d'état simplifiée pour comprendre le fonctionnement du code.

```mermaid
stateDiagram-v2
    [*] --> Initialisation

    Initialisation --> AttenteTiretteNonPosee
    state AttenteTiretteNonPosee {
        [*] --> VerifierBouton
        VerifierBouton --> CalibrationBarillet : Bouton appuyé
        CalibrationBarillet --> VerifierBouton : calibrerBarillet()
        VerifierBouton --> DefinirStrategie : Définir la stratégie
        DefinirStrategie --> VerifierBouton
        VerifierBouton --> TirettePosee : Tirette posée
    }

    TirettePosee --> EnAttenteEnlevementTirette
    EnAttenteEnlevementTirette --> Execution : Tirette enlevée

    state Execution {
        [*] --> VerifierArmé
        VerifierArmé --> VerifierObstacle : Armé == vrai
        VerifierArmé --> PasExecution : Armé == faux

        state VerifierObstacle {
            [*] --> ObstacleDétecté
            ObstacleDétecté --> AgirObstacle : Obstacle détecté
            AgirObstacle --> ArreterRobot
            ArreterRobot -->VerifierArmé
            ObstacleDétecté --> PasObstacle : Pas d'obstacle détecté
            PasObstacle --> VerifierEvenement
        }

        VerifierEvenement --> VerifierTimer
        VerifierTimer --> FaireDesPas 
        FaireDesPas --> VerifierArmé 
    }

    Execution --> [*] : Fin du programme

``` 

### Outils logiciels

- **[Visual Studio Code](https://code.visualstudio.com/) :** Un riche éditeur de texte performant où nous venons greffer des extensions afin d'obtenir l'IDE qui nous correspond.
- **[PlatformIO](https://platformio.org/) :** Une plateforme de développement, utilisée pour notre ESP32, offrant une gestion simplifiée des bibliothèques et des outils de compilation. Cela vient sous la forme d'une extension ajoutée à VSCode.

### Bibliothèques

- **[AccelStepper](https://github.com/waspinator/AccelStepper) :** Contrôle des moteurs pas à pas avec des fonctionnalités avancées comme l'accélération et la décélération. Nous l'utilisons pour la partie [steppers](./Steppers_Pamis.html).
- **[Adafruit_PWMServoDriver](https://github.com/adafruit/Adafruit-PWM-Servo-Driver-Library) :** Pour controler les servo via le PCA
- **[RPLIDAE](https://github.com/robopeak/rplidar_arduino) :** Pour la lecture du LIDAR

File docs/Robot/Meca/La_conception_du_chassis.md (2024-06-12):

---
layout: default
grand_parent: Robot
parent: La Mécanique du robot
nav_order: 2
title: La conception du chassis
---

<style>
	.video-container {
		position: relative;
		padding-bottom: 56.25%; /* Ratio 16:9 */
		height: 0;
		overflow: hidden;
		max-width: 100%;
		background: #000;
	}

	.video-container video {
		position: absolute;
		top: 0;
		left: 0;
		width: 100%;
		height: 100%;
	}
</style>

# Le châssis

## Comment fabriquer un bon châssis ?

Le châssis constitue la pièce maîtresse des robots, ayant pour rôle de supporter l'ensemble de leur masse tout en fournissant une structure robuste et rigide.
Un châssis de qualité est indispensable pour assurer la stabilité et la résistance du robot pendant ses déplacements et ses interactions avec l'environnement.

Un châssis bien conçu permet de répartir efficacement les charges et les contraintes sur l'ensemble du robot, réduisant ainsi les risques de déformation ou de rupture.
Il doit être capable de supporter les forces et les vibrations générées par les mouvements du robot, ainsi que les charges supplémentaires, telles que les capteurs, les actionneurs et les batteries.

Pour garantir la performance, la stabilité et la durabilité d'un robot, un châssis de qualité est essentiel.
Sa conception doit être minutieuse, en prenant en compte les contraintes mécaniques auxquelles le robot sera soumis et les exigences spécifiques de la tâche à accomplir.

La première étape consiste à identifier tous les éléments qui devront être fixés sur le châssis. Pour ce robot, la liste est la suivante :

- **Bille folle** : Permet des rotations efficaces du robot.
- **Le barillet** : fixation du moteur du bariellet au châssis.
- **Les MakerBeam** : Permettent la fixation du châssis avec les différentes planches de rigidification.
- **Supports moteurs** : Permettent la fixation des moteurs au châssis.
- **Support batterie** : Permet la fixation de la batterie au châssis.

En prenant en compte ces éléments, le châssis doit être conçu pour optimiser la répartition des charges et assurer la robustesse nécessaire au bon fonctionnement du robot.

# La conception du châssis

## Différentes étapes de développement

### <ins>Holonome ou Différentiel ?</ins>

La première étape du développement a consisté à décider entre une base roulante holonome et une transmission différentielle.

Un <ins>robot holonome</ins> est un type de robot dont les systèmes de déplacement permettent une mobilité dans toutes les directions de manière indépendante et instantanée. Cette capacité est obtenue grâce à l'utilisation de roues spéciales, telles que les roues omnidirectionnelles ou les roues Mecanum, qui peuvent générer des vecteurs de mouvement dans plusieurs directions. Les caractéristiques techniques et les avantages d'un robot holonome incluent :  

- Mobilité omnidirectionnelle : Permet des mouvements latéraux, diagonaux, en rotation sur place, et combinés, offrant une grande flexibilité dans des environnements complexes.  
- Contrôle de mouvement précis : Les systèmes de commande peuvent calculer et exécuter des trajectoires complexes, facilitant les manœuvres dans des espaces restreints.
- Complexité mécanique et algorithmique : Nécessite des algorithmes avancés pour coordonner les mouvements des roues et garantir des déplacements fluides et précis.  

Les robots holonomes sont souvent utilisés dans des applications où la capacité à se déplacer librement dans toutes les directions est cruciale, comme dans la robotique de service, la logistique intérieure, et les compétitions de robotique.

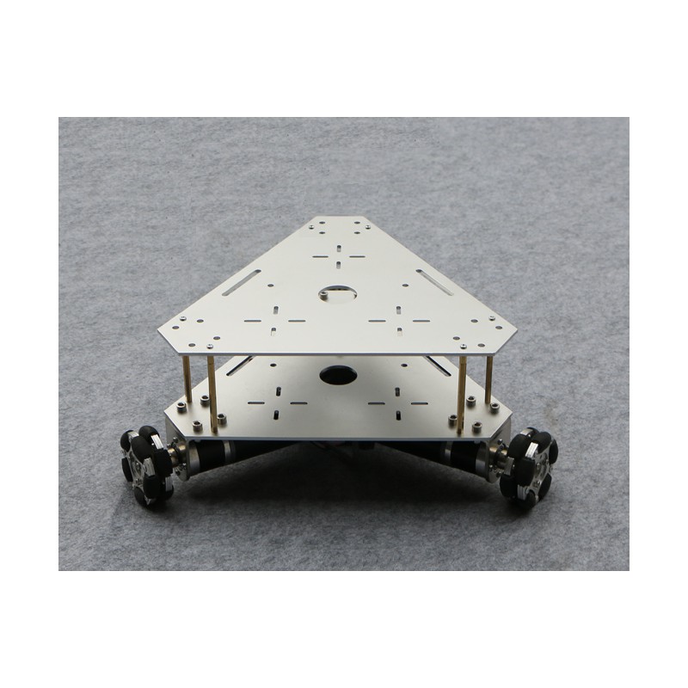
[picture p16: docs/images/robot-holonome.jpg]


Un <ins>robot différentiel</ins> utilise un mécanisme de transmission où les roues motrices sont fixées de manière indépendante, généralement sur les côtés gauche et droit du robot. La direction et la vitesse du mouvement sont contrôlées en variant les vitesses relatives de ces roues. Les caractéristiques techniques et les avantages d'un robot différentiel incluent :  

- Simplicité mécanique : La conception est généralement plus simple, avec deux moteurs contrôlant deux roues principales, souvent accompagnées de roues passives ou de roulettes pour la stabilité.  
- Facilité de contrôle : La navigation est basée sur des commandes simples de vitesse différentielle, où la différence de vitesse entre les roues gauche et droite permet de tourner.  
- Fiabilité et robustesse : Moins de composants mécaniques complexes réduisent les points de défaillance potentiels, ce qui améliore la robustesse et la maintenance.  

Les robots différentiels sont largement utilisés dans la robotique mobile.

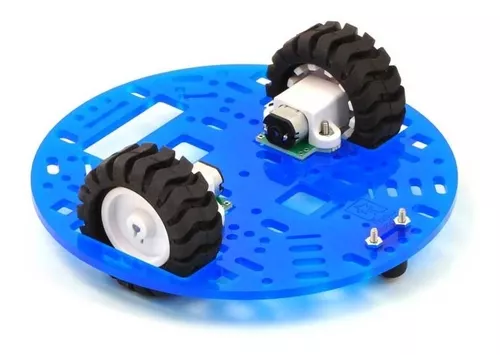
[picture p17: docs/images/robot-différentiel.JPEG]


Le premier prototype utilisait une base roulante holonome pour permettre au robot de se mouvoir dans toutes les directions, avec un châssis triangulaire et des extrémités modulables.

Suite à divers tests, une base roulante en transmission différentielle a été choisie pour optimiser l'espace de stockage des plantes en utilisant deux moteurs.

Le choix d'une transmission différentielle pour la base roulante de notre projet présente plusieurs avantages importants, particulièrement dans le contexte d'optimisation de l'espace de stockage des plantes. Voici une argumentation détaillée :

#### <ins>Maniabilité et Précision :</ins>

Une transmission différentielle, utilisant deux moteurs, permet un contrôle précis de chaque roue. Cela signifie que la base roulante peut effectuer des virages sur place (pivotement), ce qui est essentiel dans des espaces restreints comme ceux souvent rencontrés dans des installations de stockage de plantes. Cette maniabilité permet une utilisation plus efficace de l'espace disponible, réduisant les besoins en allées larges et optimisant la disposition des plantes.

#### <ins>Efficacité de l'Espace :</ins>

L'utilisation de deux [moteur pas-à-pas](../Hardware/Hardware.html) pour une transmission différentielle permet une conception compacte de la base roulante. Contrairement à des systèmes de transmission plus complexes ou volumineux, la transmission différentielle peut être intégrée dans des structures plus petites, laissant plus de place pour les plantes elles-mêmes. Cela est crucial pour maximiser la capacité de stockage sans sacrifier la mobilité ou la performance.

#### <ins>Simplicité Mécanique et Maintenance :</ins>

Les systèmes de transmission différentielle sont souvent plus simples à construire et à entretenir par rapport à des systèmes de transmission à plusieurs étages ou à engrenages complexes. Cette simplicité mécanique se traduit par une fiabilité accrue et une réduction des besoins de maintenance, ce qui est bénéfique pour une installation de stockage où l'accès aux mécanismes internes peut être limité.

#### <ins>Adaptabilité et Flexibilité :</ins>

Avec deux moteurs indépendants, la base roulante peut être facilement ajustée pour répondre à différentes configurations de stockage ou à des besoins spécifiques de déplacement. Par exemple, en modifiant simplement les vitesses relatives des moteurs, la base roulante peut adapter sa trajectoire pour naviguer efficacement dans divers arrangements de stockage.

#### <ins>Répartition du Poids :</ins>

La transmission différentielle permet une meilleure répartition du poids sur la base roulante. En contrôlant indépendamment chaque moteur et donc chaque roue, il est possible de maintenir une stabilité optimale même lorsque la charge est inégale, ce qui est souvent le cas dans des systèmes de stockage dynamique où les plantes peuvent être déplacées ou redistribuées fréquemment.

En conclusion, le choix d'une transmission différentielle pour la base roulante est justifié par sa capacité à optimiser l'espace de stockage des plantes grâce à une maniabilité supérieure, une utilisation efficace de l'espace, une simplicité mécanique, une adaptabilité élevée et une répartition optimale du poids. Ces avantages combinés permettent de créer un système de stockage plus efficace, flexible et facile à maintenir, répondant parfaitement aux exigences d'un environnement de stockage de plantes.

### <ins>Les roues</ins>

La conception des roues est une étape primordiale pour les déplacements du robot.
La forme et la fonctionnalité des roues influencent directement la mobilité, la stabilité et l'efficacité énergétique du robot.
À mesure que nos besoins et exigences ont évolué, la conception des roues a également subi plusieurs itérations.
En conséquence, un total de quatre versions distinctes de roues ont été créées, chacune présentant des formes et caractéristiques uniques adaptées aux divers défis rencontrés.
<div style="display: flex; justify-content: space-around;">

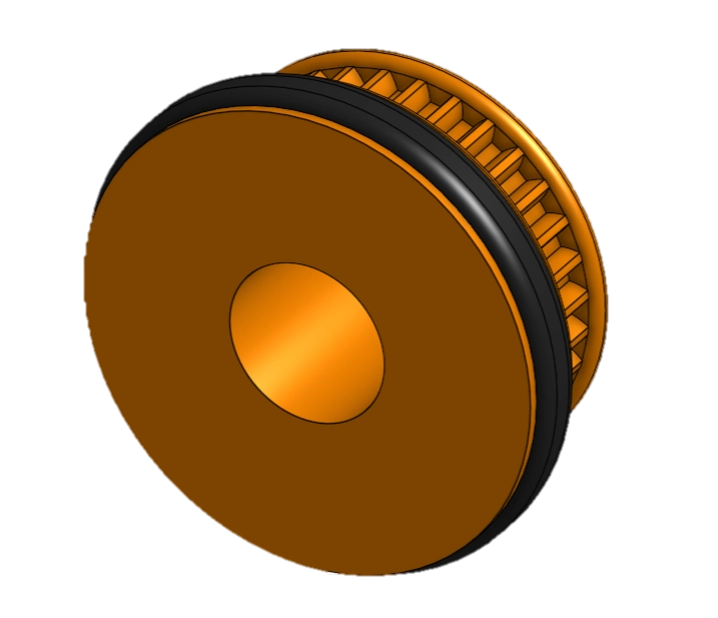
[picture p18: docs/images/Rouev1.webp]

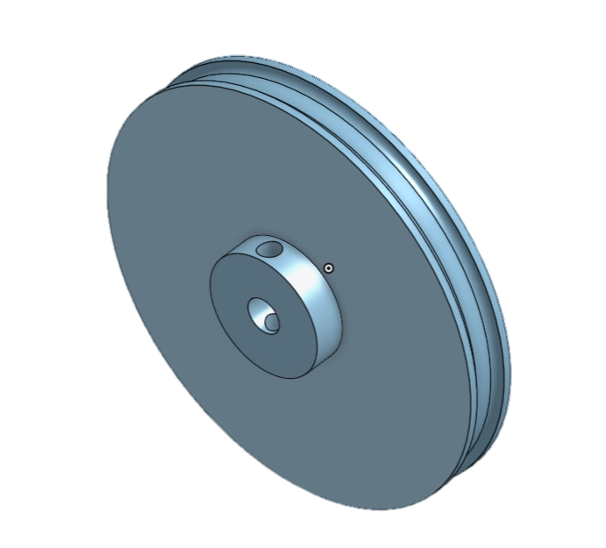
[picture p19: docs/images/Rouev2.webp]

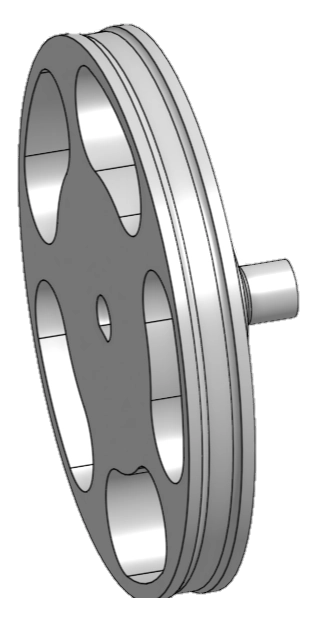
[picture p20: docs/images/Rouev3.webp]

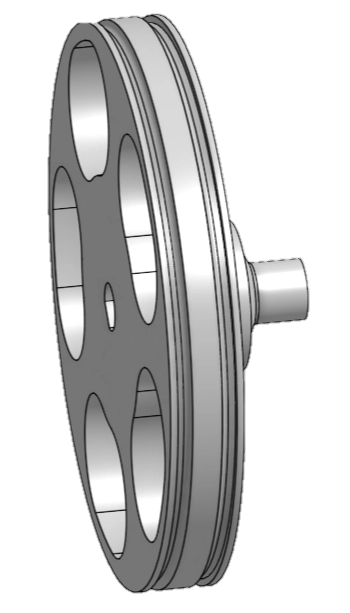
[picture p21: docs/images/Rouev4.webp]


</div>

La conception des roues a été un processus évolutif, chaque version apportant des améliorations significatives basées sur les retours des tests et les exigences opérationnelles.
Cette approche itérative a permis de développer des roues optimisées pour une performance maximale, garantissant ainsi la mobilité efficace et fiable du robot dans diverses conditions.

### <ins>Symétrie pour une meilleure stabilité</ins>

La troisième version du châssis présente une symétrie avec un espace central traversant. Un carter a été créé pour loger la carte électronique, la batterie, les boutons et le bouton d'arrêt d'urgence. Des billes folles ont été installées aux quatre coins du robot pour stabiliser les déplacements, car les roues placées au centre provoquaient un basculement avant-arrière. Les supports des billes folles peuvent également accueillir des roulements pour ne pas endommager la table.

<div style="display: flex; justify-content: space-around;">
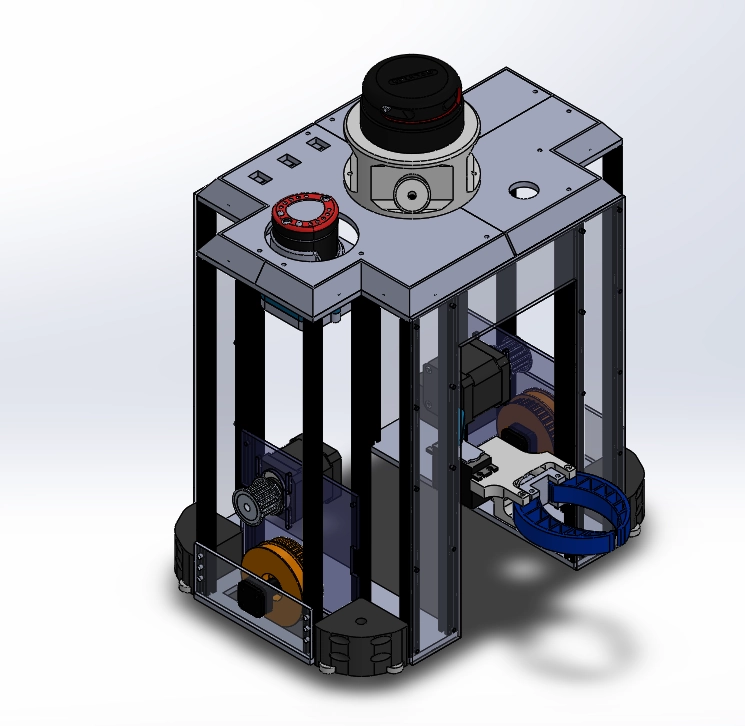
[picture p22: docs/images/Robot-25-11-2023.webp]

</div>
*(cf : 3D V3)*

### <ins>Les élements de stabilité</ins>

Afin d'assurer la stabilité du robot lors de ses déplacements, des billes folles ont été installées à l'arrière du robot et des roulements ont été fixés au support moteur à l'avant.
Cette configuration présente plusieurs avantages significatifs.

Les billes folles à l'arrière permettent une grande liberté de mouvement dans toutes les directions.
Elles réduisent la friction avec le sol et facilitent les manœuvres, surtout lors des virages serrés ou des changements de direction rapides.
De plus, elles contribuent à une meilleure répartition du poids, ce qui aide à maintenir l'équilibre du robot, notamment sur des surfaces inégales.

<div style="display: flex; justify-content: space-around;">
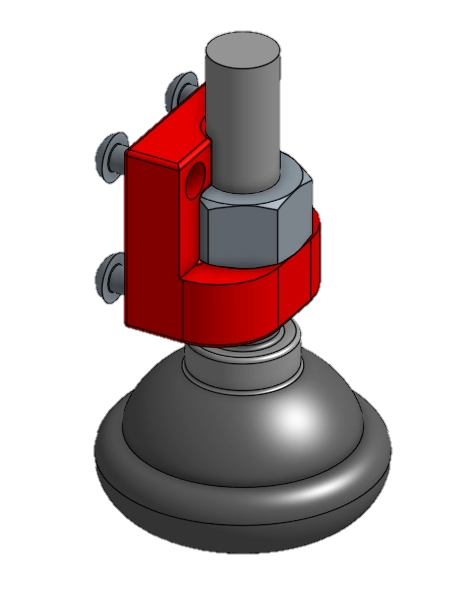
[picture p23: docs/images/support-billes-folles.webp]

</div>

Les roulements fixés au support moteur à l'avant assurent une rotation fluide et stable des roues motrices.
Ils minimisent la résistance et les pertes d'énergie, ce qui améliore l'efficacité des déplacements du robot.
En fournissant un support stable et robuste pour les roues avant, les roulements aident à maintenir une trajectoire rectiligne et à réduire les vibrations, contribuant ainsi à la précision et à la fiabilité des mouvements.

<div style="display: flex; justify-content: space-around;">
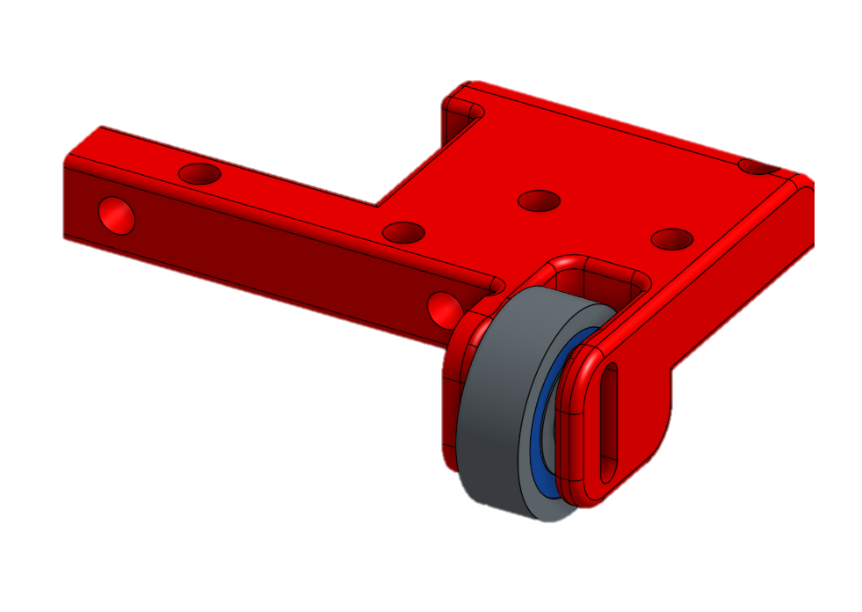
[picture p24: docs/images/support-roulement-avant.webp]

</div>

En combinant des billes folles à l'arrière et des roulements à l'avant, on obtient une solution efficace pour stabiliser le robot.
Cette approche permet de maximiser la maniabilité et la réactivité du robot tout en assurant une stabilité optimale, ce qui est essentiel pour les applications exigeant une précision élevée et une adaptabilité à différents environnements. 

### <ins>Dispositif pare-chocs</ins>

Afin de se conformer au règlement, des dispositifs pare-chocs ont été installés à l'arrière du robot et des roulements ont été placés tout autour de celui-ci pour éviter d'endommager la table de jeu.

<div style="display: flex; justify-content: space-around;">




</div>

Les pare-chocs jouent un rôle crucial dans la protection du robot et de l'environnement de jeu. En absorbant les chocs lors des recalage bordure, ils minimisent les risques de dommages à la structure du robot. De plus, en répartissant l'impact, ils contribuent à la stabilité globale du robot, permettant un fonctionnement plus fluide et fiable pendant les compétitions.

Les roulements, quant à eux, assurent une interaction douce entre le robot et la surface de la table de jeu. Ils réduisent la friction et préviennent les rayures ou autres dommages sur la surface de jeu, garantissant ainsi un environnement de compétition équitable et préservé. En protégeant à la fois le robot et la table de jeu, ces dispositifs sont essentiels pour maintenir l'intégrité et la durabilité de l'équipement, tout en respectant les exigences du règlement.

### <ins>Le carter</ins>

Afin de pouvoir fixer la carte électronique ainsi que les différents boutons et écrans, un carter a été créé à cet effet.

Le carter joue un rôle essentiel dans la protection et l’organisation des composants internes du robot.
Il offre plusieurs avantages majeurs :

- **Protection des composants électroniques** : Le carter protège la carte électronique et autres composants sensibles des impacts, de la poussière et des débris, prolongeant ainsi leur durée de vie et assurant leur bon fonctionnement.

- **Organisation interne** : En maintenant les boutons, les écrans et la carte électronique en place, le carter facilite le câblage et réduit les risques de court-circuit. Une disposition ordonnée des composants rend également la maintenance et les réparations plus simples et plus rapides.

- **Accessibilité** : Avec des ouvertures et des supports bien placés, le carter permet un accès facile aux boutons et aux écrans, améliorant ainsi l'interaction avec le robot. Cette accessibilité est cruciale pour effectuer des ajustements rapides et pour un contrôle efficace de l’appareil.

- **Esthétique et design** : Un carter bien conçu contribue à l'apparence professionnelle du robot. Il masque les composants internes tout en offrant une surface lisse et attrayante, ce qui est particulièrement important pour les robots destinés à des environnements visibles par le public.

- **Stabilité structurelle** : En intégrant le carter à la structure du robot, on peut améliorer la rigidité et la stabilité de l’ensemble, permettant ainsi un fonctionnement plus précis et fiable.

En résumé, le carter est une composante indispensable pour la protection, l'organisation et la fonctionnalité des éléments électroniques du robot, tout en contribuant à son apparence et à sa solidité globale.



### <ins>Passage à OnShape</ins>

Le passage de Solidworks à OnShape s'est fait pour plusieurs raisons pratiques :

#### <ins>Problèmes de Licence :</ins>  
Solidworks posait des problèmes de licence, ce qui limitait son utilisation. OnShape, en revanche, est gratuit pour les étudiants, rendant le logiciel accessible à toute l'équipe sans coûts supplémentaires.

#### <ins>Travail Collaboratif :</ins>  
OnShape permet le travail collaboratif en temps réel, facilitant la communication et la coordination entre les membres de l'équipe. Cette fonctionnalité est particulièrement utile pour des projets complexes nécessitant des ajustements fréquents et une collaboration constante.

#### <ins>Redéveloppement et Optimisation :</ins>  
Le passage à OnShape a entraîné le redéveloppement complet du robot, offrant l'opportunité d'améliorer et d'optimiser les composants. Par exemple, la pince ajoutée a nécessité la suppression des Makerbeam à l'avant, permettant des mouvements plus libres.

#### <ins>Consolidation et Amélioration du Châssis :</ins>  
Le châssis a été consolidé en une seule pièce pour réduire la flexibilité et augmenter la robustesse. Cette consolidation a également permis l'ajout d'un système de fixation pour le stockage des plantes, améliorant la fonctionnalité globale du robot.

## Assemblage du robot

<div class="video-container"><video muted autoplay loop><source src="../../images/Assemblage-Robot.webm" type="video/webm" /></video></div>

## Conclusion

La conception du robot est le résultat d’une approche méthodique et réfléchie visant à équilibrer efficacité, fonctionnalité et esthétique.
Chaque aspect du robot a été soigneusement planifié pour assurer une performance optimale et une facilité d'utilisation.

L'architecture du robot intègre une structure robuste et bien organisée, garantissant la protection et le bon fonctionnement des composants électroniques.
Le carter joue un rôle central en offrant une protection contre les impacts et les débris, tout en facilitant l'accès aux boutons et aux écrans pour une interaction aisée.

L’organisation interne permet un câblage ordonné, réduisant les risques de court-circuit et simplifiant la maintenance et les réparations.
De plus, la disposition des éléments internes contribue à la stabilité et à la rigidité de l’ensemble, améliorant ainsi la précision et la fiabilité du robot.

En termes d’esthétique, le design du robot assure une apparence professionnelle et moderne, masquant les composants internes tout en offrant une surface lisse et attrayante.
Cette attention à l’esthétique est particulièrement importante pour les robots destinés à des environnements visibles par le public.

En somme, la conception du robot combine ingénieusement protection, organisation, accessibilité et esthétique, résultant en un dispositif performant, durable et évolutif.
Cette réalisation témoigne de l’importance d’une planification minutieuse et d’une conception réfléchie pour créer des solutions technologiques innovantes et pratiques.

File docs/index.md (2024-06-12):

---
layout: home
nav_order: 1
title: Accueil
---

<style>
	.video-container {
		position: relative;
		padding-bottom: 56.25%; /* Ratio 16:9 */
		height: 0;
		overflow: hidden;
		max-width: 100%;
		background: #000;
	}

	.video-container video {
		position: absolute;
		top: 0;
		left: 0;
		width: 100%;
		height: 100%;
	}
</style>

# La documentation de l'équipe I3 pour la Coupe de France de robotique 2024

Bienvenue sur la page du projet de la Coupe de France de robotique. Vous y trouverez les différentes documentations ainsi que les recherches effectuées par l'équipe dans le cadre de la construction d'un robot, tout en itérant les designs.

Le robot

## À propos du projet

La Coupe de France de robotique est un événement qui a lieu chaque année à La Roche-sur-Yon. De nombreuses équipes de robotique provenant de différentes écoles d'ingénieurs ainsi que de lycées se rendent sur place pendant quatre jours pour mettre au défi leurs robots qu'elles auront conçus au cours des neuf mois précédents.

## Poster & vidéo - robot principal

Poster projet

<!-- Vidéo journée des projets sur le robot principal -->
<div class="video-container"><video controls><source src="./images/Robot.webm" type="video/webm" /></video></div>

## Poster & vidéo - PAMI

Poster PAMI

<!-- Vidéo journée des projets sur le PAMI -->
<div class="video-container"><video controls><source src="./images/pami-presentation_video.webm" type="video/webm" /></video></div>

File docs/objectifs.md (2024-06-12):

---
layout: default
nav_order: 2
title: Objectifs du projet
---

<div>
	Logo de la coupe de france de robotique
</div>

La Coupe de France de Robotique, existant depuis plus de 30 ans, est une compétition annuelle qui rassemble des équipes d'étudiants de toute la France autour d'un défi technologique : concevoir, réaliser et faire concourir un robot autonome selon un cahier des charges précis.

Participer à cette compétition offre une opportunité inestimable de mettre en pratique leurs connaissances théoriques et de développer des compétences transversales en gestion de projet et en travail d'équipe.

Au fil des années, la Coupe est devenue une référence incontournable, reconnue par les recruteurs. En effet, bon nombre des anciens participants occupent aujourd'hui des postes clés dans l'industrie et sont eux-mêmes devenus des recruteurs, cherchant des talents ayant cette expérience unique.

La présence de l’école dans cette compétition renforce son image d'excellence et d'innovation dans le domaine de la technologie et de l'ingénierie, tout en démontrant notre engagement à se préparer aux défis du monde réel.

## Contexte du Projet

Dans un contexte associatif et dans le cadre de notre parcours d'études en ingénierie, nous cherchons à améliorer nos compétences en robotique grâce à un projet concret, une possibilité offerte par la Coupe de France de Robotique. 

Tout au long du projet, nous avons été amenés à effectuer des recherches pluridisciplinaires, tout en utilisant les ressources disponibles (internet, contacts).

## Objectifs du Projet

En neuf mois, l'équipe a construit un robot capable de réaliser plusieurs tâches :

- Prendre une plante et la planter dans un potager ou une jardinière selon la couleur.
- Mettre la plante dans un pot et la planter partout.
- Tourner le panneau solaire vers la couleur de son camp.
- Être actif pendant 90 secondes.

Particularité de cette année, lors de la compétition, des petits robots appelés PAMI peuvent également effectuer plusieurs tâches :

- Se déplacer à la 90e seconde et s'éteindre au bout de 100 secondes.
- Être dans une zone spécifique.
- Toucher une plante.

Table de match

# Existant

De nombreux robots existent déjà. Le robot actuel est basé sur des robots à motorisation différentielle réalisés auparavant par l'ancien club A.R.E.A.

# Cahier des Charges

Le cahier des charges est en partie imposé par le règlement de la Coupe de France de Robotique, que vous pouvez retrouver dans le PDF suivant.

<embed src="./files/Eurobot2024_Rules.pdf" type="application/pdf" width="100%" height="600px" />

[Réglement de la Coupe de France de robotique](https://www.coupederobotique.fr/wp-content/uploads/Eurobot2024_Rules_CUP_FR_FINAL.pdf)

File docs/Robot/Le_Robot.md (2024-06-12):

---
layout: technicals
title: Robot
nav_order: 3
has_children: true
---

# Le robot principal

<model-viewer src="./RobotModels/Robot.gltf" ar ar-modes="webxr scene-viewer quick-look" camera-controls tone-mapping="neutral" poster="./RobotModels/RobotPoster.webp" shadow-intensity="0" exposure="0.62" shadow-softness="0" style="display: block; margin-left: auto; margin-right: auto; height: 600px; width:600px;">
    <div class="progress-bar hide" slot="progress-bar">
        
    </div>
</model-viewer>

## Introduction

### Missions

Le robot commence dès le démarrage d'un match. En quittant sa zone de départ, il a le choix de réaliser trois tâches :

<div style="display: flex; justify-content: space-around;">



</div>

Prendre des plantes, prendre des pots et tourner les panneaux solaires.
À la fin du match, le robot doit se trouver dans une zone différente de sa zone de départ.

### Contraintes

Le robot est autorisé à :

- Manipuler les éléments.
- Voler des plantes des zones non protégées.
- Tourner les panneaux solaires de sa couleur de match et les panneaux partagés.

Le robot n'est pas autorisé à :

- Nuire à l'adversaire.
- Défendre une zone volontairement.
- Voler des plantes dans les jardinières.
- Heurter l'adversaire.

Dans la suite de la documentation, vous verrez les différents actionneurs, capteurs et microcontrôleurs utilisés pour le robot.

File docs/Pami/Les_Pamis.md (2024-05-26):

---
layout: default
title: PAMI
nav_order: 4
has_children: true
---

# PAMI

Le PAMI dans son milieu naturel

## Introduction

### Mission

Le PAMI n'entre en jeu qu'à partir de la 90e seconde d'un match. Il quitte sa zone de départ et a 10 secondes pour aller toucher une plante ou un pot contenant la plante dans une zone de dépose (action de polliniser). Enfin, il doit rester au contact de la plante jusqu'à la fin du match.

### Contraintes

Il peut :
- être touché par le robot de son équipe, mais pas manipulé.
- se déployer dans la limite d'une augmentation de 10 cm de son périmètre.

Il ne peut pas :
- amener une plante dans une zone.
- sortir une plante d'une zone (invalidation de l'action du PAMI le cas échéant).
- réaliser ses actions dans une zone adverse (points pour l'équipe adverse le cas échéant).
- collisionner un robot autre que celui de son équipe (pressage du bouton d'arrêt d'urgence et disqualification le cas échéant).

De plus, la stratégie développée pour le PAMI varie selon le côté du terrain où il commence. Nous devons donc être capables de sélectionner la bonne stratégie avant le début du match.

En résumé, le PAMI doit pouvoir se déplacer d'un point A (sa zone de départ) à un point B (sa jardinière), en pollinisant une plante dans sa jardinière (contact) et en restant à ses côtés jusqu'à la fin du match.

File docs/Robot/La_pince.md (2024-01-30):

---
layout: default
parent: Robot
nav_order: 2
title: La pince
---
## Tout sur la pince que j'ai pour toi

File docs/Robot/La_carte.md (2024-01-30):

---
layout: default
parent: Robot
nav_order: 1
title: Guide de Syntaxe Markdown
---
## tout sur la carte de jeux

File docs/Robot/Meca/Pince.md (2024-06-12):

---
layout: default
grand_parent: Robot
parent: La Mécanique du robot
nav_order: 3
title: Système de Manipulation des éléments de jeu
---

<style>
	.video-container {
		position: relative;
		padding-bottom: 56.25%; /* Ratio 16:9 */
		height: 0;
		overflow: hidden;
		max-width: 100%;
		background: #000;
	}

	.video-container video {
		position: absolute;
		top: 0;
		left: 0;
		width: 100%;
		height: 100%;
	}
</style>

# Objectifs du système

L'objectif de la pince est de manipuler les éléments de jeu de la Coupe de France de Robotique 2024. Ces éléments comprennent de petits pots ronds métalliques (environ 6 cm de diamètre et 6,5 cm de hauteur) et des fleurs en plastique légèrement plus petites. De petits panneaux solaires doivent également être manipulés.

<div style="display: flex; justify-content: space-around;">





</div>

Les mâchoires doivent être capables de saisir aussi bien les pots métalliques que les plantes, malgré leurs différences de taille et de poids. Ces éléments doivent ensuite être déplacés depuis le terrain de jeu jusqu'à la zone de dépôt. La stratégie choisie par l'équipe consiste à stocker les éléments de jeu à l'intérieur du robot. Pour ce faire, le système doit pouvoir se lever, se baisser et s'orienter à un angle d'environ 120° par rapport au point de saisie de l'élément. Il est important de noter que l'élément peut être saisi en face ou sur le côté du robot. En termes de précision, celle-ci doit être suffisante pour positionner les éléments de jeu à quelques millimètres près dans les emplacements prévus à l'intérieur du robot. Ce système doit également être rapide car le temps est très limité (90 secondes). Plus le système sera rapide, plus le robot pourra marquer de points et ainsi augmenter ses chances de remporter la compétition.

## Aperçu de la pince et de son rôle

Pour répondre à ces objectifs, plusieurs modèles ont été conçus et testés. Ci-dessous, vous trouverez le modèle retenu :

Image de la pince

La pince à donc été conçu de sorte à pouvoir manipuler les éléments de jeu. Une fois l'élément saisi, les mâchoires peuvent se lever avec celui-ci et s'orienter vers l'intérieur du robot pour y déposer les plantes. Les éléments de jeu, qu'il s'agisse de plantes ou de pots métalliques, peuvent alors être stockés dans un barillet. Ce barillet est capable de contenir 4 éléments, ce qui réduit le nombre de manipulations nécessaires et optimise ainsi le temps de jeu.

# Spécifications techniques

## Contraintes et exigences spécifiques à la Coupe de France de Robotique 2024

Les contraintes spécifiques à la Coupe de France de Robotique concernent principalement la taille du robot et de ses systèmes embarqués, ainsi que l'exécution rapide des tâches, étant donné la durée limitée de l'épreuve. Afin de répondre à la contrainte de taille, le système doit être le plus compact possible ou optimiser l'utilisation des espaces disponibles dans le châssis. Par ailleurs, un robot rapide requiert une plus grande puissance des moteurs ce qui impact donc l'alimentation.

Parmi les autres contraintes, figure l'obligation de concevoir un robot entièrement autonome. Cela nécessite de connaître en temps réel la position des moteurs, notamment celle de la pince, et de pouvoir automatiser ces mouvements grâce à une carte programmée. Le robot doit également disposer de sa propre source d'alimentation électrique. Ce critère est à prendre en compte car en fonction des technologies utilisées, il sera nécéssaire d'en adapter également l'alimentation. Par chance les élements de jeu à manipuler sont très léger, de l'ordre de quelque grammes par éléments. Cela joue en la faveur d'une consommation d'énergie moindre. 

## Exigences de performance

La performance du système sera principalement évaluée en fonction de sa vitesse. Sur le terrain de jeu, il y a 36 pots et 36 plantes répartis dans des zones prédéfinies. Pour transporter l'intégralité des pots avec les plantes à l'intérieur, il faut effectuer 72 mouvements pour les stocker et 72 mouvements pour les vider. En 90 secondes, cela laisse peu de temps pour chaque mouvement de montée et de descente du système. Il est clair que cette objectif sera difficile à atteindre, notamment en tenant compte du temps de déplacement jusqu'aux zones prévues. Cependant, l'objectif est de s'en rapprocher le plus possible.

Quant à la précision, seule la rotation autour de l'axe Y doit être précise. La précision sur l'axe Z (la hauteur) est de moindre importance pour le système, une marge d'erreur de plusieurs milimètre est largement tolérable. De même, les mâchoires n'ont pas besoin d'une grande précision. Leur matériau souple (TPU) et leur forme permettent d'absorber les éventuels défauts de précision.

Pour effectuer ces mouvements, des servos moteur ont été utilisés avaec deux référence différentes : 
	- MG996R
	- FS5115M

C'est éléments ont été choisie pour leur rapport puissance/taille/prix/facilité d'utilisation qui est excellant pour notre application.

Pour plus d'information, il est possible de consulter la partie adware de la documentation technique ou les documentation technique des produits concernés. 

[Documentation technique FS5115M](https://www.pololu.com/product/3426)

[Documentation technique MG996R](https://www.electronicoscaldas.com/datasheet/MG996R_Tower-Pro.pdf)

[Documentation technique Hardware](../Hardware/Hardware.html)

# Conception du système de pince

### Conception des mâchoires

Dès les premières preuves de concept (POC), le système de manipulation des éléments s'est orienté vers un dispositif de pince afin de s'adapter aussi bien à la taille des plantes qu'à celle des pots métalliques. Grâce à l'utilisation du TPU, un matériau souple et déformable, la pince peut s'ajuster à n'importe lequel des objets à manipuler, garantissant ainsi une prise adéquate et empêchant la chute des éléments lors des déplacements.

La forme de la pince est restée relativement constante au fil des versions, mais elle a néanmoins subi de nombreux ajustements. 

<div style="display: flex; justify-content: space-around;">



</div>

La première amélioration apportée a été d'incliner la surface en contact avec les éléments de jeu afin de mieux épouser leur forme. Une rainure a également été ajoutée pour permettre de bloquer les éléments de jeu à l'intérieur de celle-ci grâce à leur forme particulière. En effet, les pots à manipuler présentaient une boursouflure sur leur partie supérieure. De plus, la pince a été allégée en retirant certains de ses renforts intérieurs pour la rendre plus souple. Ce besoin est apparu en raison du changement de TPU utilisé dans les imprimantes 3D. Le nouveau TPU était beaucoup plus rigide, il a été nécessaire d'adapter les machoires pour conserver leur flexibilités.

<div style="display: flex; justify-content: space-around;">



</div>

La troisième version visait à affiner les mâchoires, car il s'est avéré qu'il n'était pas nécessaire de maintenir une épaisseur importante comme dans les versions précédentes. Cette épaisseur permettait de faire épouser la forme de l'éléments à la machoires or lors du retrait des renforts, cette fonction était moins efficace. En effectuant des tests, il a été convenue que cette forme n'était pas obligatoire. Les éléments de jeu étaientt également très bien pris avec la troisèmes forme développés. 

<div style="display: flex; justify-content: space-around;">



</div>

Comme on peut le constater, les mâchoires ont été affinées progressivement au cours des essais, toujours dans le but de gagner de l'espace. Diverses combinaisons ont également été explorées pour trouver le niveau de souplesse le plus adapté.

### Conception des Actionneurs

Un premier mécanisme de serrage a été largement étudié avant d'aboutir au modèle final. Celui-ci se caractérisait par l'utilisation d'un seul moteur pour actionner les mâchoires. Le moteur agissait sur un axe servant de levier pour celles-ci. Cependant, ce système ne permettait pas de contrôler chaque mâchoire indépendamment, mais était plus léger car il nécessitait un seul moteur. En revanche, il présentait un empattement important pour une force de serrage limitée en raison de l'axe sur lequel le moteur agissait.

<div style="display: flex; justify-content: space-around;">



</div>

<div class="video-container"><video muted autoplay loop><source src="../../images/pince/video1_actionneur1.webm" type="video/webm" /></video></div>

<div class="video-container"><video muted autoplay loop><source src="../../images/pince/video2_actionneur1.webm" type="video/webm" /></video></div>

Ensuite, un deuxième moteur a été ajouté pour les mâchoires, ce qui a considérablement simplifié le système et augmenté la force de serrage. Désormais, un moteur était directement connecté à chaque mâchoire via le palonnier. Cependant, cette modification a rendu le système beaucoup plus lourd en raison de l'ajout d'un moteur, et les éléments se sont rapprochés les uns des autres, créant ainsi un contact entre eux.

Ce contact entre les éléments a entravé la manipulation correcte des objets sur le terrain. Pour remédier à cela, des entretoises ont été ajoutées pour abaisser les mâchoires par rapport aux moteurs. Cela a permis de positionner le système au-dessus du moteur responsable de la rotation, réduisant ainsi considérablement l'empattement à l'intérieur du robot.

<div class="video-container"><video muted autoplay loop><source src="../../images/pince/MOUVEMENT MACHOIRE.webm" type="video/webm" /></video></div>

Pour déplacer les plantes jusqu'au barillet, un servo-moteur identique à ceux déjà utilisés a été ajouté. Cette fois également, plusieurs versions ont été étudiées. La première était adaptée au premier mécanisme d'actionneur, qui présentait un effet de levier assez important en raison de l'empattement du mécanisme et nécéssitait en conséquence un renfort au niveau des axes de rotation.

<div style="display: flex; justify-content: space-around;">



</div>

Comme on peut l'observer, le poids du système exercé sur le moteur est réparti sur deux points de fixation, situés au-dessus et en dessous, afin de prévenir tout dommage au moteur.

Suite au remplacement des actionneurs (ajout du deuxième moteur), le mécanisme a été adapté.

Grâce à la proximité des moteurs contrôlant les mâchoires (réduction de l'effet de levier), il n'était plus nécessaire d'ajouter un support supplémentaire. En d'autres termes, les mâchoires ont été directement montées sur le palonnier du moteur permettant la rotation. Le principe de fonctionnement est demeuré inchangé entre les deux versions.

<div class="video-container"><video muted autoplay loop><source src="../../images/pince/Rotation_actionneur.webm" type="video/webm" /></video></div>

### Conception de l'ascenseur

Le choix du système d'ascenseur s'est fait parmi deux mécanismes distincts. Le premier envisageait l'utilisation d'une tige filetée actionnée par un moteur brushless, avec des capteurs poussoirs déterminant les positions haute et basse. Cependant, ce système présentait des inconvénients majeurs par rapport à celui actuellement retenu. Parmi ceux-ci, on peut citer la complexité de l'alimentation des moteurs brushless et l'incapacité à définir plusieurs positions (d'un point de vue programmation) sans recourir à un encodeur, ce qui aurait considérablement compliqué la programmation.

Ainsi, le mécanisme permettant le déplacement des mâchoires vers le haut et vers le bas a été orienté vers l'utilisation d'un servomoteur et d'un bras de levier montés sur un rail linéaire. Ce dernier se compose de deux éléments : un rail en aluminium et un patin en plastique autolubrifié, s'emboîtant l'un dans l'autre pour permettre un glissement fluide. Ce produit est fourni par notre sponsor IGUS. Sa caractéristique principale est de minimiser les pertes dues aux frottements tout en offrant une durée de vie similaire à celle des systèmes entièrement métalliques, et ce, sans nécessiter de lubrification.

<div class="video-container"><video muted autoplay loop><source src="../../images/pince/RAIL LINEAIRE.webm" type="video/webm" /></video></div>

Le système de mâchoires a été solidement fixé sur le patin, permettant ainsi un déplacement fluide vers le haut ou vers le bas le long du rail, sans nécessiter l'application d'une force significative.

<div style="display: flex; justify-content: space-around;">



</div>

En effectuant une rotation, le moteur élève le reste du système. L'évolution de ce mécanisme a consisté à doubler la longueur du bras de levier pour renforcer sa structure et à intégrer plusieurs perforations afin de tester la relation entre la force du moteur et la longueur du bras. Ce système présente l'avantage d'être facile à manipuler, relativement rapide, compact et de n'occuper de l'espace qu'en hauteur, à l'emplacement du servomoteur, qui est généralement la zone la moins sollicitée du robot.

Ainsi, en ajoutant le bras de levier, le système devient entièrement contrôlable sur trois axes.

<div class="video-container"><video muted autoplay loop><source src="../../images/pince/Mouvement rail Igus.webm" type="video/webm" /></video></div>

# Tests et validation

### Procédure de validation

Pour valider le système de pinces, à chaque itération, les différentes pièces nécessaires ont été imprimées puis testées dans toutes les situations possibles. Cela a commencé par la reproduction manuelle des mouvements ou des effets du mécanisme. Si l'essai était validé, un test était ensuite réalisé avec des servomoteurs contrôlés via une petite carte et un potentiomètre. Enfin, si les essais précédents étaient concluants, le système était testé avec un programme. Les modifications éventuelles étaient alors apportées au système, déclenchant à nouveau la procédure de test depuis le début, jusqu'à obtenir le système final.

### Résultats

Voici une vidéo du robot utilisant la pince pour charger et décharger les plantes en plastique ainsi que les pots. Dans cette vidéo, une seule pince est en fonctionnement pour illustrer son mécanisme. La vidéo a également été ralentie afin de mieux observer les différents mouvements. En réalité, lors de la compétition, deux pinces fonctionnaient simultanément pour permettre au robot de manipuler un plus grand nombre d'éléments de jeu en même temps.

<div class="video-container"><video muted autoplay loop><source src="../../images/pince/fonc_pince.webm" type="video/webm" /></video></div>

Lors de la compétition, le système a répondu aux exigences du cahier des charges. En effet, il a pu manipuler les plantes avec suffisamment de précision pour les prendre et les déposer aux endroits souhaités. Le système s'est parfaitement comporté avec le barillet et s'est avéré relativement rapide. Cependant, nous avons constaté que d'autres systèmes étaient beaucoup plus adaptés que le nôtre. Ces autres systèmes avaient la particularité de prendre plusieurs plantes en même temps. Bien qu'ils étaient moins précis et auraient endommagé de vraies plantes, ils répondaient mieux aux exigences de la compétition.

De plus, lors de la compétition, les températures élevées ont provoqué une déformation majeure des mâchoires en TPU, les rendant moins efficaces qu'à l'origine.

## Perspectives pour l'avenir

Une première amélioration possible serait de remplacer le barillet par deux autres pinces presque identiques à celles actuellement sur le robot. Cela permettrait de supprimer le moteur d'orientation vers le barillet, ce qui aurait réduit le temps nécessaire pour les actions de jeu. Cela permettrait également de manipuler les plantes par quatre, simplifiant ainsi la programmation et améliorant la fiabilité du système en réduisant le nombre de mouvements à effectuer. L'utilisation de ce système présenterait également l'avantage de nécessiter peu de modifications par rapport au système actuel, sans nécessiter d'investissements importants en termes de temps.

Dans une perspective d'avenir, il serait envisageable d'utiliser un système de pince permettant de saisir plusieurs éléments de jeu en même temps, de supprimer le barillet actuel et de le remplacer par une deuxième pince équivalente pour doubler le nombre d'éléments de jeu manipulables avant chaque dépôt dans les zones prévues à cet effet.

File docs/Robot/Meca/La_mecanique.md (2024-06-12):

---
layout: default
parent: Robot
has_children: true
nav_order: 1
title: La Mécanique du robot
---

# La Mécanique du Robot

## Introduction

### L'objectif du robot

L'objectif du robot est de se déplacer sur la table de jeu de la Coupe de France de Robotique 2024, tout en embarquant toute l'électronique nécessaire à son bon fonctionnement. Le robot doit être capable de se déplacer sans problème malgré les différents dispositifs transportés.

## Spécification technique

### Contraintes et exigences spécifiques à la Coupe de France de Robotique 2024

Les contraintes spécifiques à la Coupe de France de Robotique sont principalement liées à la taille du robot et de ses systèmes embarqués. Le robot doit respecter un périmètre non déployé de 1200 mm et un périmètre déployé de 1300 mm, avec une hauteur limitée à 350 mm. La base roulante doit être la plus légère possible afin d'optimiser les performances des moteurs.

### Exigences de performance

Lors de la conception du robot, l'objectif était d'obtenir un robot suffisamment compact pour respecter les contraintes dimensionnelles. Le robot doit être capable de transporter au moins 6 plantes ou 4 pots, justifiant le choix d'un [barillet](../Meca/Le_barillet.md). Pour les déplacements, il est nécessaire de disposer d'une vitesse adéquate et d'un moyen de connaître la position de manière relativement précise. Les [moteur pas-à-pas](../Hardware/Hardware.html) ont été choisis à cet effet.

## Plan des parties suivantes

### Choix des matériaux

Dans cette section, nous examinerons les différents matériaux sélectionnés pour la construction du robot.
Nous comparerons les avantages et les inconvénients des matériaux utilisés, en tenant compte des critères de résistance, de poids et de coût.
Une attention particulière sera portée aux innovations matérielles permettant d'améliorer les performances globales du robot.

### Conception du châssis

Nous détaillerons ici le processus de conception du châssis, en expliquant les choix structuraux et les décisions prises pour assurer une répartition optimale des charges et des contraintes.
Cette partie inclura également une discussion sur les techniques de fabrication utilisées pour obtenir un châssis robuste et léger.

### Système de stockage des éléments de jeu 

Cette page présente les détails techniques du système de stockage, également appelé barillet, destiné aux plantes en plastique et aux pots. Elle explique en détail les différents prototypes ainsi que les améliorations apportées à ce système.

### Système de manipulation des éléments de jeu

Cette section abordera les différentes stratégies et mécanismes utilisés pour manipuler et transporter les éléments de jeu.
Nous analyserons les dispositifs de préhension, les mécanismes de levage et les systèmes de stockage, en mettant l'accent sur leur efficacité et leur fiabilité.

## Conclusion

La conception et la réalisation d'un robot performant pour la Coupe de France de Robotique 2024 impliquent une réflexion approfondie sur plusieurs aspects clés.
Dans cette introduction, nous avons présenté l'objectif principal du robot ainsi que les spécifications techniques et les exigences de performance nécessaires pour réussir cette compétition.
Les sections suivantes détailleront le système de manipulation des éléments de jeu, la conception du châssis et le choix des matériaux, offrant une vue d'ensemble complète des défis et des solutions apportées pour optimiser les capacités du robot.
Cette approche holistique garantit que tous les aspects critiques sont soigneusement considérés, permettant ainsi de maximiser les chances de succès lors de la compétition.

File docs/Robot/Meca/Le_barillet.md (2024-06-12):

---
layout: default
grand_parent: Robot
parent: La Mécanique du robot
nav_order: 3
title: Système de stockage des éléments de jeu
---

<style>
	.video-container {
		position: relative;
		padding-bottom: 56.25%; /* Ratio 16:9 */
		height: 0;
		overflow: hidden;
		max-width: 100%;
		background: #000;
	}

	.video-container video {
		position: absolute;
		top: 0;
		left: 0;
		width: 100%;
		height: 100%;
	}
</style>

# Objectifs du système

L'objectif du barillet est de stockée les éléments de jeu de la Coupe de France de Robotique 2024. Ces éléments comprennent de petits pots ronds métalliques (environ 6 cm de diamètre et 6,5 cm de hauteur) et des fleurs en plastique légèrement plus petites (de l'ordre de quelque militmètre).

<div style="display: flex; justify-content: space-around;">





</div>

## Aperçu du barrilet et de son rôle

Durant les phases de match, le robot va se déplacer sur le terrain et prendre les pots et les plantes puis les amener à un autre endroit.
Le but étant de stocker les pots et plantes à l'intérieur du robot via le barillet puis de les restituer une fois la zone de dépose atteinte de sorte à limiter les aller retour. Le tout en s'adaptant à la vitesse des pinces.

<div class="video-container"><video muted autoplay loop><source src="../../images/barillet/animation_barillet.webm" type="video/webm" /></video></div>

# Spécifications techniques

## Contraintes et exigences spécifiques à la Coupe de France de Robotique 2024

Les exigences spécifiques à la Coupe de France de Robotique 2024 concernent principalement les dimensions du robot et de ses composants embarqués, ainsi que la rapidité d'exécution des tâches en raison du temps limité de l'épreuve. Pour respecter la contrainte de taille, le système doit être aussi compact que possible et optimiser l'espace disponible dans le châssis. De plus, un robot rapide nécessite des moteurs plus puissants, ce qui affecte l'alimentation électrique. Parmi les autres exigences, il y a l'obligation de créer un robot entièrement autonome. Cela implique de surveiller en temps réel la position du barillet et d'automatiser ses mouvements à l'aide d'une carte programmée.

## Exigences de performance

Les performances du barillet sont principalement évaluées par sa vitesse et sa capacité à stocker des pots. Le barillet doit en effet stocker le plus de pots possible afin de minimiser les allers-retours. Parallèlement, il doit s'adapter à la taille restreinte du robot et aux zones où les pinces peuvent déposer les plantes. Il doit également être capable de connaître en permanence la position du barillet pour le placer correctement par rapport aux pinces et aux emplacements libres.

# Conception du barillet

## Les différents prototypes 

Pour stocker les éléments de jeu à l'intérieur du robot, deux systèmes ont été imaginés :

  - *Le premier prototype* est basé sur un axe horizontal autour duquel les éléments de jeu tournent. Ce système est similaire à celui utilisé à l'avant des moissonneuses-batteuses.

<div style="display: flex; justify-content: space-around;">



</div>

  - *Le deuxième* système repose sur un axe verticale en rotation autour duquel les éléments de jeu sont placés. 

<div style="display: flex; justify-content: space-around;">



</div>

La rotation du système est assurée par un moteur pas à pas (stepper) qui permet de connaître en temps réel la position de l'axe, à condition qu'aucun pas n'ait été sauté et que la position de départ soit connue. Bien qu'il aurait été possible d'utiliser un servomoteur à 360°, ce type de moteur n'était pas disponible dans le stock de l'association, contrairement au moteur pas à pas.

Le fonctionnement du système est simple : un moteur pas à pas fait tourner une platine sur laquelle sont déposés les pots. Une fois qu'un élément de jeu est déposé ou pris, le moteur tourne pour permettre l'accès à l'emplacement suivant.

## Système de stockage à axe horizontal

Ce système permet de faire tourner les éléments de jeu autour d'un axe horizontal, similaire au fonctionnement de l'avant d'une moissonneuse. Avec deux emplacements côte à côte pour les éléments de jeu, il aurait été possible de faire passer entre six et huit plantes/pots.

Plusieurs prototypes de ce système ont été réalisés. Le premier prototype comportait quatre emplacements de stockage. Cependant, l'espace disponible étant très limité, le système aurait été difficilement adaptable au robot en raison des contraintes d'espace à l'intérieur de celui-ci. Il aurait été nécessaire d'agrandir le châssis, ce qui aurait été incompatible avec les dimensions requises.

<div style="display: flex; justify-content: space-around;">



</div>

Le deuxième prototype comportait trois branches et pouvait s'intégrer dans le robot. Cependant, lors des tests, il a été constaté que les axes permettant le mouvement des espaces de stockage ne permettaient pas à la pince de placer les éléments de jeu à leurs emplacements dédiés. Pour remédier à ce problème, une troisième version a été conçue avec deux branches, dont la forme était optimisée pour ne pas gêner les mâchoires des pinces.

<div style="display: flex; justify-content: space-around;">



</div>

Pour la rotation du mécanisme, l'utilisation d'un moteur pas à pas ou d'un servomoteur était envisageable. Les deux options étaient valables. Le servomoteur présentait l'avantage d'être plus compact et plus facile à utiliser par rapport au moteur pas à pas. Cependant, bien que le moteur pas à pas soit plus volumineux et moins puissant que le servomoteur, il permettait une rotation infinie.

Néanmoins, ce système nécessitait soit un axe reliant les deux côtés du rabatteur, soit un deuxième moteur pour éviter que les pièces en mouvement ne se bloquent entre elles. L'utilisation d'un axe aurait nécessité un agrandissement du système, ce qui n'était pas envisageable dans notre cas. Par conséquent, il aurait été nécessaire d'utiliser deux moteurs. Cependant, même avec deux moteurs, le système restait peu fiable. C'est pourquoi il a été décidé de conserver le barillet avec un axe vertical.

## Système de stockage à axe vertical

Comme mentionné précédemment, ce prototype reposait sur un axe horizontal autour duquel les éléments de jeu auraient tourné. Idéalement, ce prototype aurait comporté deux à trois étages, en fonction de l'espace disponible sur le robot. Les éléments de jeu auraient été déposés successivement au premier, au deuxième, puis au troisième étage afin de maximiser la capacité de stockage.

Cependant, les tests ont démontré l'impossibilité d'inclure plusieurs étages en raison des dimensions du châssis, du positionnement des autres composants du robot et des pinces déjà construites. Par conséquent, il a été décidé de limiter le stockage des éléments de jeu à un seul étage. Pour compenser le manque d'étages, la possibilité de disposer le maximum de pots autour de l'axe a été étudiée. Selon les espacements théoriques sur les logiciels de conception, il a été déterminé que le nombre maximal de pots se situait entre quatre et six.

Les essais effectués en association avec la pince ont révélé que le nombre maximum de pots réalisable était de quatre. Bien qu'il soit théoriquement possible d'en placer six, des imprécisions dans le système de pince ont rendu cette configuration impraticable. En effet, la dépose des éléments de jeu n'était jamais parfaitement répétable en raison des déformations des mâchoires en TPU, qui variaient selon la position du pot lors de sa saisie.

<div style="display: flex; justify-content: space-around;">



</div>

Un espaceur permet la liaison entre le moteur et la platine en la surélevant simultanément. Cela empêche les éléments de jeu d'entrer en contact avec le moteur.

### <ins>***Prototype N°1 :*** </ins>

<div style="display: flex; justify-content: space-around;">



</div>

Lors des premiers essais, le moteur pas à pas initialement utilisé (NEMA 17 PANCAKE : 17HS086-1004S) a été remplacé en raison de sa puissance insuffisante. Il a été substitué par un moteur pas à pas NEMA 17 plus puissant, également disponible au sein de l'association. Ce changement de taille n'a pas posé de problème, car la différence entre les deux moteurs était minime. De plus, l'utilisation d'un unique étage pour le stockage a permis de libérer de l'espace en hauteur.

Pour plus d'information concernant les moteurs pas à pas, il est possible de consulter la page dédiés au hardware : [moteur pas-à-pas](../Hardware/Hardware.html)

autrement vous pouvez retrouver la documentation technique des moteurs pas à pas ici : 

[NEMA 17 PANCAKE](https://www.omc-stepperonline.com/download/17HS08-1004S.pdf)

[NEMA 17](https://www.omc-stepperonline.com/download/17HS16-2004S1.pdf)

### <ins>***Prototype N°2 :***</ins>

<div style="display: flex; justify-content: space-around;">



</div>

Ce prototype repose donc sur un nouveau moteur plus imposant. Dans cette version, le spacer a été réduit en taille et l'emplacement des éléments de jeu a été resserré pour pouvoir accueillir à la fois des plantes en plastique et des pots métalliques.

### <ins>***Prototype N°3 :***</ins>

<div style="display: flex; justify-content: space-around;">



</div>

Finalement, sur le système final, la platine a été fermée afin d'empêcher l'éjection des éléments lors de la rotation. La forme d'accueil des éléments de jeu est devenue ovale et a été élargie pour offrir plus de flexibilité lors de la dépose des éléments. Une deuxième platine a été ajoutée en dessous pour soutenir les éléments de jeu, ceux-ci n'étant plus maintenus par la platine supérieure.

De plus, une petite cale a été ajoutée pour guider les éléments de jeu lors de leur dépose dans le barillet, évitant ainsi qu'ils ne soient mal placés.

<div style="display: flex; justify-content: space-around;">





</div>

Un capteur a également été ajouté pour obtenir une position de référence et la maintenir à chaque initialisation du robot. Pour ce faire, un simple aimant a été positionné sur la platine. Lorsque celui-ci passe devant le capteur, la position de référence est atteinte.

<div style="display: flex; justify-content: space-around;">



</div>

# Tests et validation

Finalement le système avec un axe horizontal à été choisie. Avant d'avoir un système fiable en association avec la pince, il a fallu faire de nombreux essaie de sorte à avoir la taille parfaite des emplacements pour les éléments de jeu. Il à également était nécessaire de programmer la position de référence grâce au capteur. Le capteur détecter la présence de l'aimant avant que celui-ci ne soit au centre, une correction en terme de rotation à donc été ajouté pour corriger ce manque. 

## Résultats 

<div class="video-container"><video muted autoplay loop><source src="../../images/pince/fonc_pince.webm" type="video/webm" /></video></div>

Lors de la compétition, le barillet a pu garantir une fiabilité irréprochable dans les actions qu'il devait effectuer. Aucune modification n'a dû être apportée une fois sur place et aucun composant n'a posé de problème.

## Perspectives pour l'avenir

Pour améliorer ce système, il pourrait être envisageable d'ajouter un étage de sorte à stockée plus de pot. Pour cela le système ne subirait pas de gros changement, les plus gros changement serait à effectuer sur le chassis ainsi que sur la pince pour gagner de la place en hauteur. Gagner de la place en hauteur est tout à fait possible car la hauteur du chassis est très largement inférieur au maximum autorisé par le reglement. Cela n'avait pas été fait dues à la taille des makerbeam disponible au seins de l'association.

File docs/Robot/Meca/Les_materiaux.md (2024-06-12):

---
layout: default
grand_parent: Robot
parent: La Mécanique du robot
nav_order: 1
title: Le choix des matériaux
---

# Le choix des matériaux

Dans cette section, nous examinerons les différents matériaux sélectionnés pour la construction du robot.
Nous comparerons les avantages et les inconvénients des matériaux utilisés, en tenant compte des critères de résistance, de poids et de coût.
Une attention particulière sera portée aux innovations matérielles permettant d'améliorer les performances globales du robot.

La question du choix des matériaux pour la construction du robot a été la première à se poser. Ce n’est pas une décision facile à prendre car plusieurs options sont disponibles :

- **PLA** : Ce plastique est utilisé par les imprimantes 3D, mais il est assez long à imprimer.
- **TPU** : Un plastique flexible utilisé par les imprimantes 3D, offrant des propriétés élastiques intéressantes.
- **Planches de bois** : Faciles à découper avec une découpeuse laser.
- **laques d'acrylique** : Transparentes et également faciles à découper.

## Mais quel(s) matériau(x) choisir ?

Le PLA semble être une bonne idée pour imprimer le châssis et l’ensemble des structures en une seule fois. Cependant, plusieurs problèmes apparaissent rapidement :

- **Temps d’impression** : Pour des pièces de grande taille comme le châssis ou les côtés, le temps d’impression dépasse 10 heures, augmentant ainsi le risque d'échec. De plus, cela devient une réelle perte de temps lors des différents essais.
- **Consommation** : Plus la durée d’impression est élevée, plus la consommation de PLA augmente. Sachant que la plupart des pièces doivent être refaites plusieurs fois avant d’atteindre la version optimale, la consommation devient importante.

En résumé, le PLA fera perdre énormément de temps sur des pièces non adaptées alors qu’il existe de meilleures alternatives. Cela dit, ce matériau sera tout de même utilisé pour de petites pièces rapides à imprimer.

Le TPU est une autre option intéressante, en raison de sa flexibilité et de ses propriétés élastiques. Cependant, il présente des défis similaires à ceux du PLA en termes de temps et de consommation d’impression. De plus, sa flexibilité peut ne pas convenir à toutes les parties du robot.

Les planches de bois de 3 mm constituent le meilleur choix pour ce robot. Elles sont faciles et rapides à découper avec une découpeuse laser. Il suffit de générer un fichier au format .DXF et la découpeuse produit le motif sur la planche de bois. C’est un moyen précis d’obtenir les pièces désirées et en cas de légers problèmes, le bois est facile à travailler : possibilité de découper à nouveau, de poncer, de perforer, etc. Pour certaines plaques, nous avons choisi des planches de 5 mm afin d'obtenir une structure plus rigide.

La dernière option est la plaque d’acrylique de 3 mm, aussi efficace que la planche de bois mentionnée précédemment, mais avec un temps de découpe environ trois fois plus long. Cela dit, le rendu du motif est tout aussi précis, avec en plus une touche de modernité selon la couleur choisie. Ce matériau sera utilisé pour le châssis afin de permettre l’observation de l’intérieur du robot et de vérifier le bon emplacement des différentes pièces.

## Les coûts des matériaux

Un autre facteur crucial dans le choix des matériaux est le coût. Chaque matériau présente des avantages spécifiques, mais il est important de considérer leur coût pour rester dans le budget du projet.

- **PLA** : Le PLA est relativement abordable, ce qui en fait un choix populaire pour l'impression 3D. Cependant, en raison de la consommation élevée nécessaire pour imprimer de grandes pièces et du risque de devoir refaire plusieurs impressions, les coûts peuvent rapidement s'accumuler. De plus, le temps d’impression prolongé se traduit indirectement par des coûts supplémentaires en termes de consommation énergétique et d'usure des équipements.

- **TPU** : Le TPU est plus cher que le PLA, principalement en raison de ses propriétés élastiques uniques. Bien que sa flexibilité puisse être bénéfique pour certaines applications, le coût plus élevé et le temps d'impression comparable à celui du PLA en font une option moins économique pour la majorité des pièces du robot.

- **Planches de bois** : Les planches de bois, surtout celles de 3 mm et 5 mm, sont très économiques. Le bois est non seulement abordable, mais il permet également de réaliser des découpes rapides et précises avec une découpeuse laser, ce qui réduit les coûts de production en termes de temps et d’énergie. En outre, les erreurs peuvent être corrigées facilement et à moindre coût, ce qui n'est pas le cas avec les matériaux plus coûteux comme le PLA ou le TPU.

- **Plaques d'acrylique** : Les plaques d’acrylique sont plus chères que le bois, mais elles offrent des avantages esthétiques et pratiques, tels que la transparence et la possibilité d’observer l’intérieur du robot. Le temps de découpe plus long peut augmenter légèrement les coûts opérationnels, mais l'acrylique reste une option viable pour des pièces spécifiques où ces caractéristiques sont cruciales.

En résumé, tout en tenant compte des propriétés spécifiques et des avantages techniques de chaque matériau, le coût reste un facteur déterminant. Pour ce projet, les planches de bois apparaissent comme la solution la plus économique et pratique, mais l'acrylique sera utilisé de manière pour ses propriétés transparentes. Le PLA et le TPU, bien que potentiellement utiles, sont moins économiques et seront donc réservés à des usages spécifiques où leurs propriétés sont indispensables.

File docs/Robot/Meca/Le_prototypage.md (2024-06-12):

---
layout: default
grand_parent: Robot
parent: La Mécanique du robot
nav_order: 4
title: Le prototypage du robot
---

# Le prototypage du robot

Le premier prototype utilisait une base roulante holonome pour permettre au robot de se mouvoir dans toutes les directions, avec un châssis triangulaire et des extrémités modulables.



*(cf : V1 modulable 3D).*

Suite à divers tests, une base roulante en transmission différentielle a été choisie pour optimiser l'espace de stockage des plantes en utilisant deux moteurs.

## Optimisation de la forme et de l'espace de stockage

Un prototype a été développé pour respecter le périmètre maximal de 1200 mm lorsque les actionneurs sont rétractés. Le robot devait avoir un centre creux pour stocker les plantes et les pots, pouvant accueillir 3 pots alignés.



*(cf : V2 arc de triomphe).*

Le châssis de cette version était constitué de Makerbeam et équipé de moteurs Nema 17 et de roues.

## Symétrie pour une meilleure stabilité

La troisième version du châssis présente une symétrie avec un espace central traversant. Un carter a été créé pour loger la carte électronique, la batterie, les boutons et le bouton d'arrêt d'urgence. Des billes folles ont été installées aux quatre coins du robot pour stabiliser les déplacements, car les roues étant placées au centre provoquaient un basculement avant-arrière. Les supports des billes folles peuvent également accueillir des roulements pour ne pas endommager la table.



*(cf : 3D V3).*

#### <ins>Réorganisation Interne :</ins>  
La batterie a été déplacée à l'arrière, libérant de l'espace pour une carte électronique plus grande. Cette réorganisation a optimisé l'utilisation de l'espace et amélioré la performance du robot.

En résumé, le passage à OnShape a permis de surmonter les limitations de Solidworks, d'améliorer la collaboration et de redévelopper le robot de manière plus efficace et fonctionnelle.



*(cf : 3D V4)*

### <ins>Prototype fonctionnel avec Nema 23</ins>

Les tests ont révélé que les moteurs [Nema 17](../Hardware/Hardware.html) étaient insuffisants. Les moteurs [Nema 23](../Hardware/Hardware.html) en transmission directe ont été adoptés. Les roulements à l'avant ont remplacé les billes folles pour stabiliser le robot et optimiser l'espace de stockage.

Le robot fonctionne maintenant en 24V avec deux batteries placées à l'arrière. Le carter repose sur quatre pièces imprimées en 3D accueillant l'électro-aimant pour la tirette, un connecteur pour l'alimentation, une prise USB pour l'ESP32 et divers boutons.



*(cf : 3D V5)*

### <ins>Version finale</ins>

La version finale respecte une charte visuelle définissant les couleurs : l'acrylique est noir ou gris fumé transparent et les pièces imprimées en 3D sont rouges. Les actionneurs, les pinces et le barillet ont été finalisés. Des poignées ont été ajoutées pour faciliter le transport, et les roues ont été modifiées pour s'incruster dans des roulements fixés

 dans la plaque d'acrylique. Des roulements ont été placés aux quatre coins pour protéger la table de jeu, et des cales ont été ajoutées à l'arrière pour limiter les chocs lors des recalages en bordure.



*(cf : 3D VF)*
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

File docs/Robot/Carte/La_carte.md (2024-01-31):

---
layout: default
parent: Robot
has_children: true
nav_order: 1
title: La carte
---
## tout sur la carte de jeux

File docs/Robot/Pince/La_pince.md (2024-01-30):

---
layout: default
parent: Robot
nav_order: 2
title: La pince
has_children: true
---
## Tout sur la pince que j'ai pour toi

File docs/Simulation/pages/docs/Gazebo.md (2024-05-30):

---
layout: default
parent: Simulation
nav_order: 2
title: Gazebo
---

## Qu'est-ce que Gazebo ?

Gazebo, initialement nommé Gazebo Project, est un simulateur 3D, cinématique, dynamique et multi-robot permettant de simuler des robots articulés dans des environnements complexes, intérieurs ou extérieurs, réalistes et en trois dimensions.

Voici quelques caractéristiques clés de Gazebo :

- **Simulateur 3D et Multi-Robot :** Gazebo permet de créer des environnements virtuels tridimensionnels où des robots peuvent évoluer. Il prend en compte la cinématique et la dynamique des robots, ce qui permet de simuler leurs mouvements et interactions.
- **Compatibilité avec ROS et Player :** Gazebo peut être utilisé conjointement avec ROS (Robot Operating System) et Player. Il est possible d’utiliser les API de ROS pour transmettre des données entre les robots et la simulation.
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

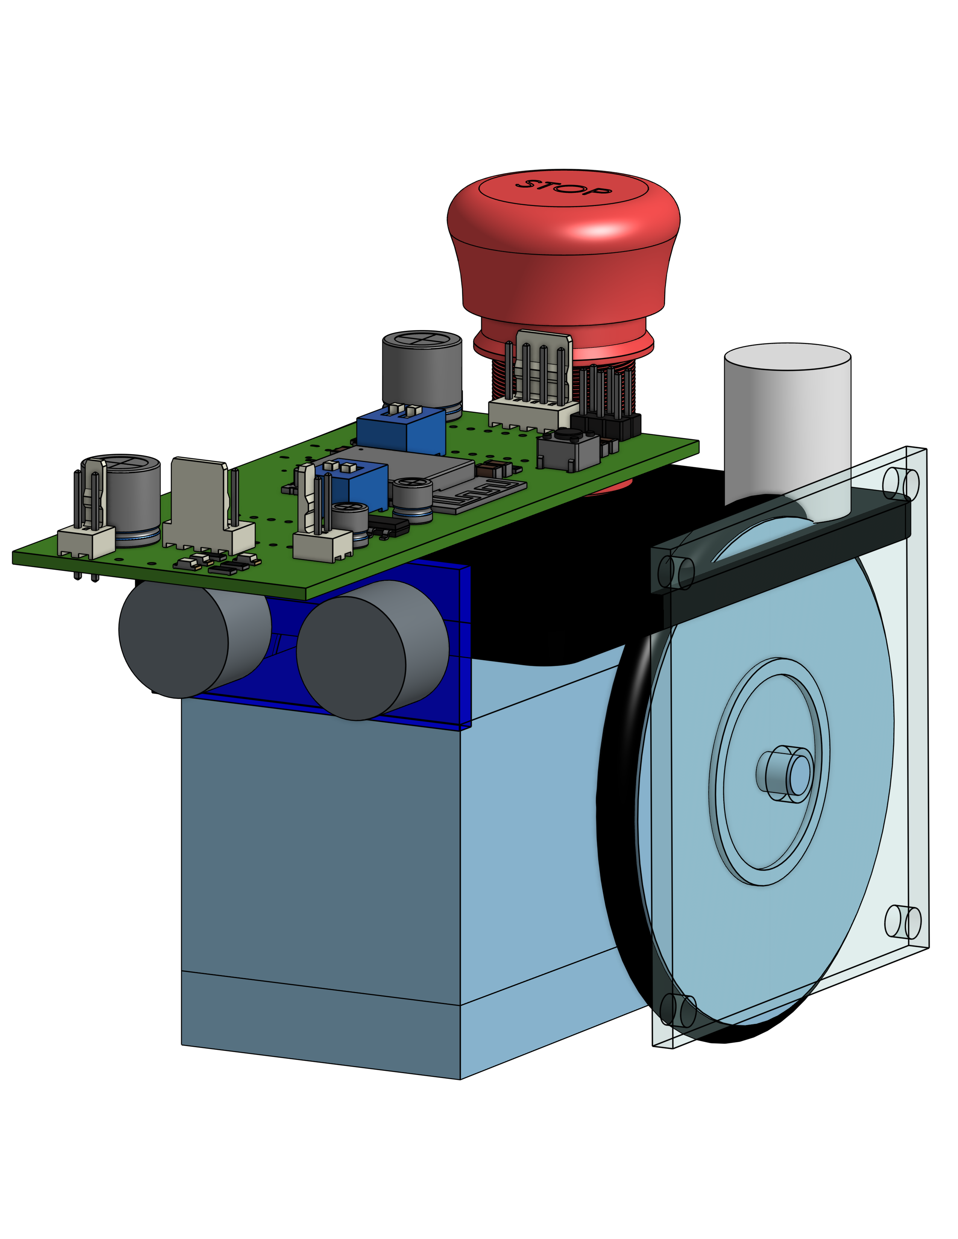
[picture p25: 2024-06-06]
docs/Pami/conception_files/3d_files/poster1.webp

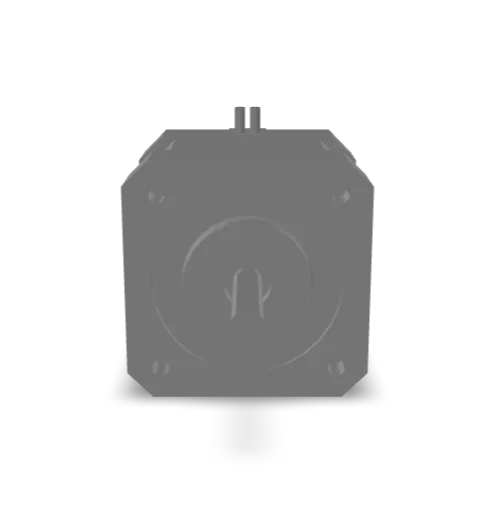
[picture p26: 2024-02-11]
docs/Robot/Hardware/Hardware_files/poster.webp

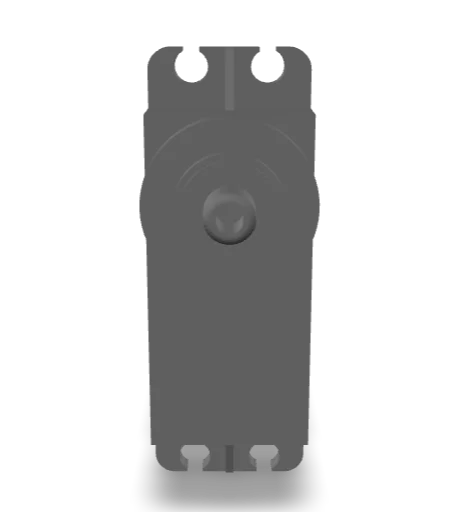
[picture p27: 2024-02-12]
docs/Robot/Hardware/Hardware_files/posterServo.webp

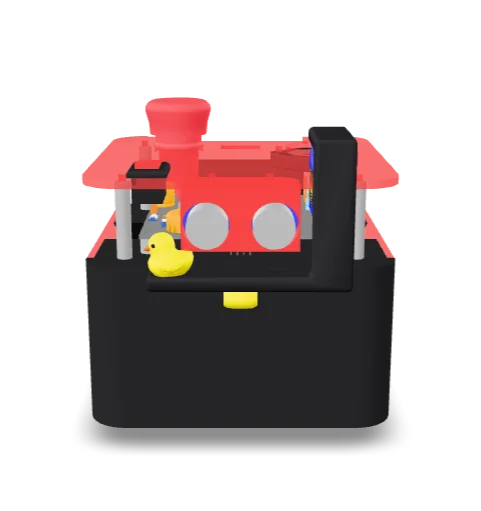
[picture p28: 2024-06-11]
docs/Pami/conception_files/3d_files/v3.webp

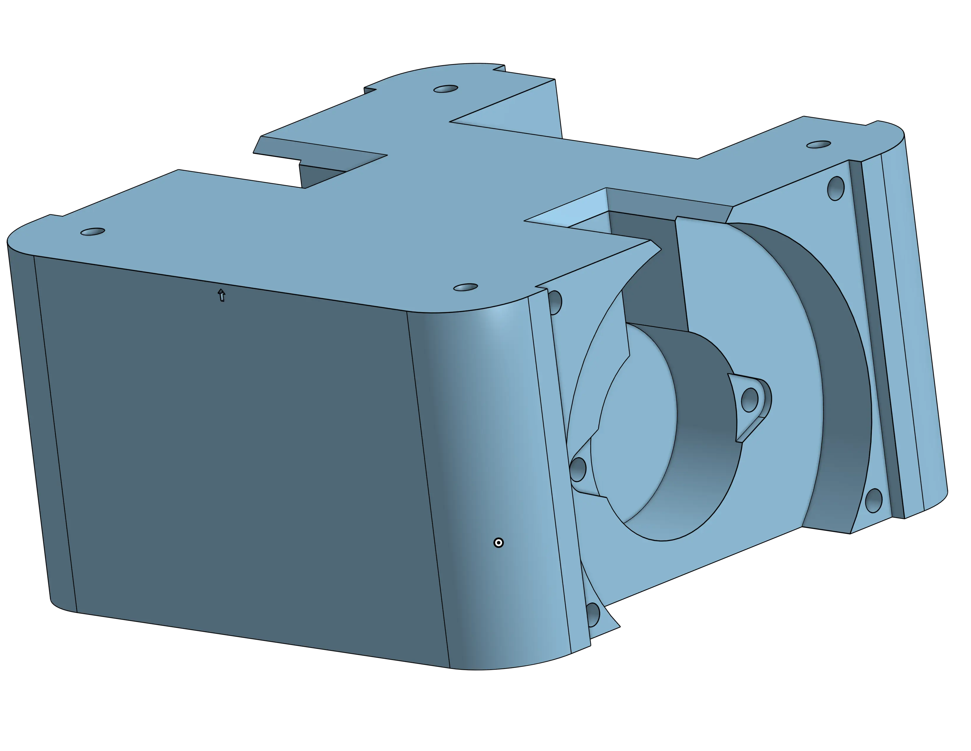
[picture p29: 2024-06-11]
docs/Pami/conception_files/3d_files/v2body.webp

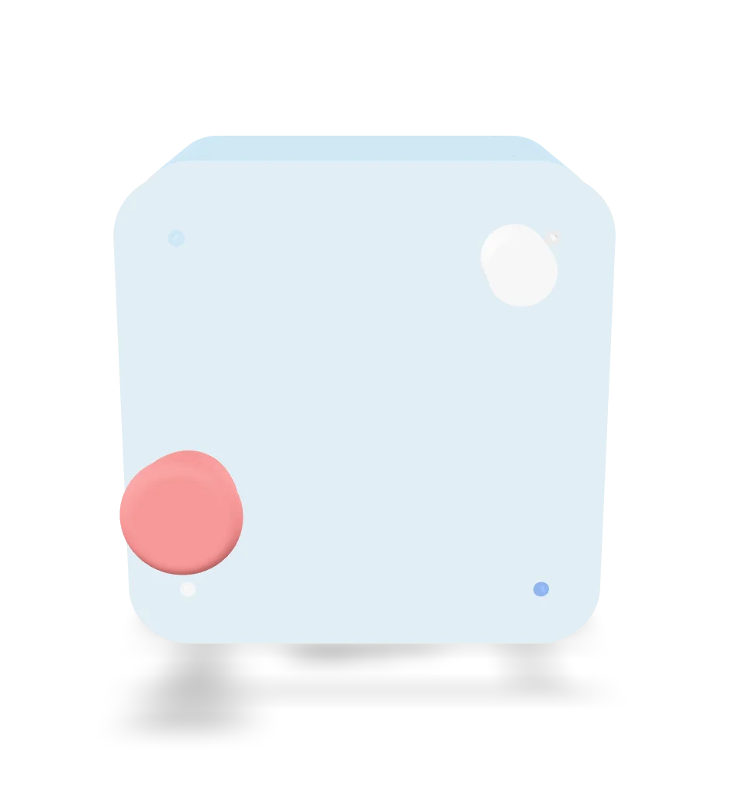
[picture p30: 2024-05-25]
docs/models/poster_v2.webp

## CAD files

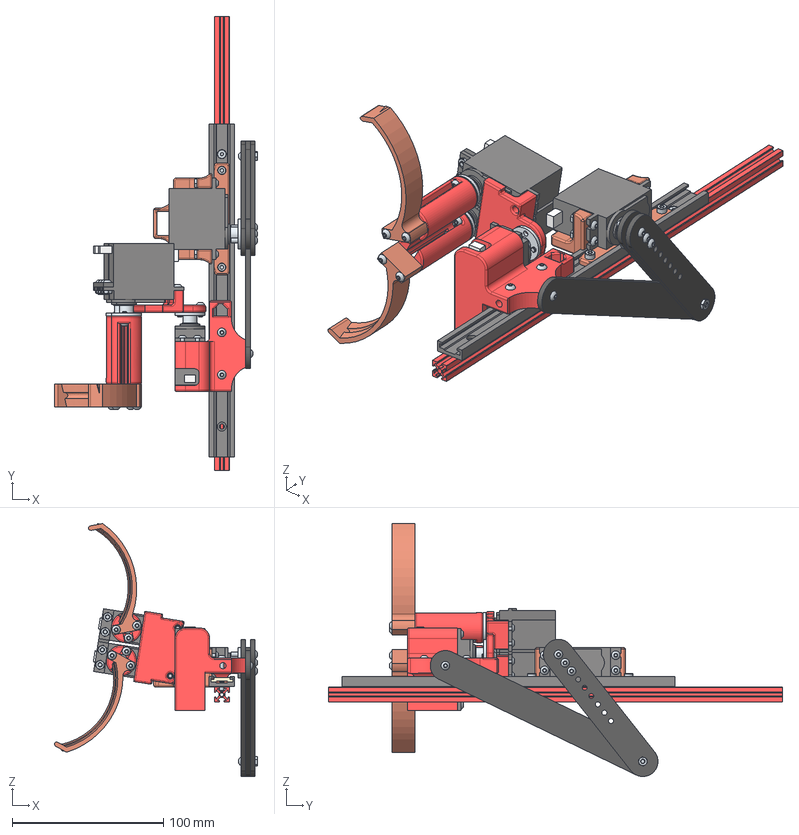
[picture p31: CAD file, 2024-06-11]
project/Robot_principal_model3D/Assemblage pince gauche.step
134.2 x 300.0 x 167.2 mm
Socket button head screw M3x0.5 x 8 x 21
Socket button head screw M3x0.5 x 20 x 4
Spaceur 2 x 2
Socket button head screw M3x0.5 x 14 x 4
Hex thin nut grade A & B M3 x 9
Hex socket head cap screw M3x0.50 x 10 x 2
Palonnier rond x 4
Socket button head screw M3x0.5 x 16 x 5
Pince V3 gauche
Socket button head screw M3x0.5 x 10
Chamfered plain washer normal M3 x 2
Support moteur gauche
bras liaison moteur
Hex socket countersunk head screw M3x0.5 x 5 x 2
Entretoise 3mm
Maintient moteur Z
Pince B3 Droite
makerbeam 10x10x300.stp<1>
Liaison moteur rotation pince

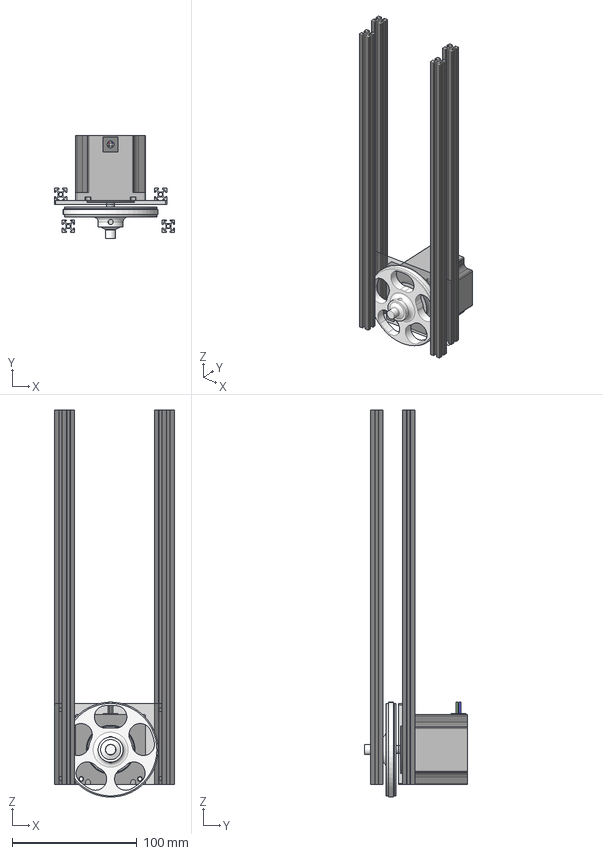
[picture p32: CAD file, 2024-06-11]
project/Robot_principal_model3D/Assembly transmission.step
96.2 x 82.1 x 309.8 mm
support stepper
MB300 x 4
NEMA 23 23HS20-2004S
ROUE 2

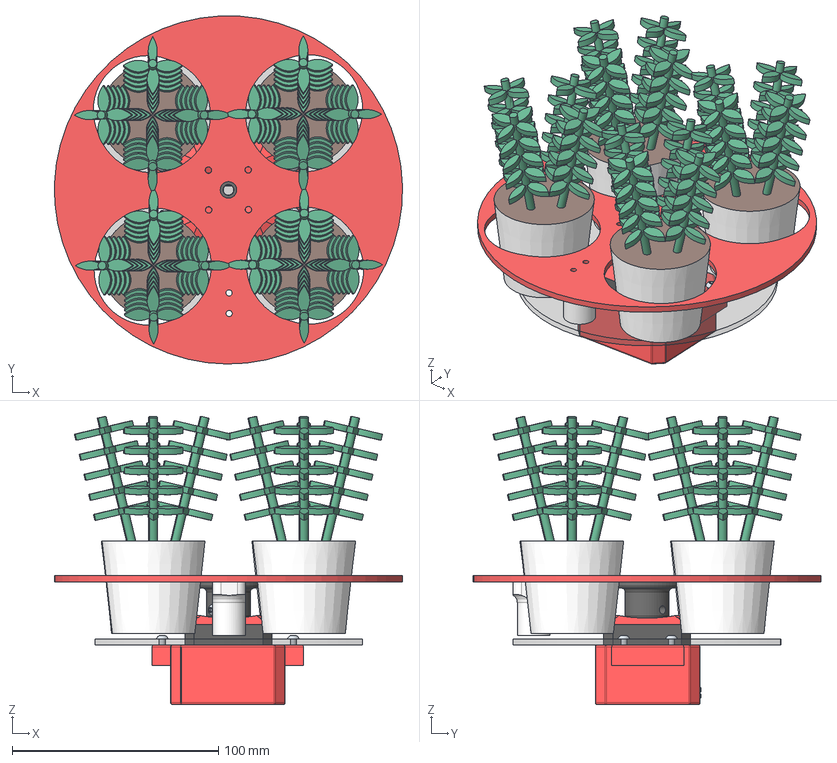
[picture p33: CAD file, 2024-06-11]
project/Robot_principal_model3D/Assembly barrilet.step
168.9 x 168.9 x 140.0 mm
Socket button head screw M3x0.5 x 10 x 5
Barillet 4 plante
support NEMA 17
plante x 4
spaceur 15.5
support aimant

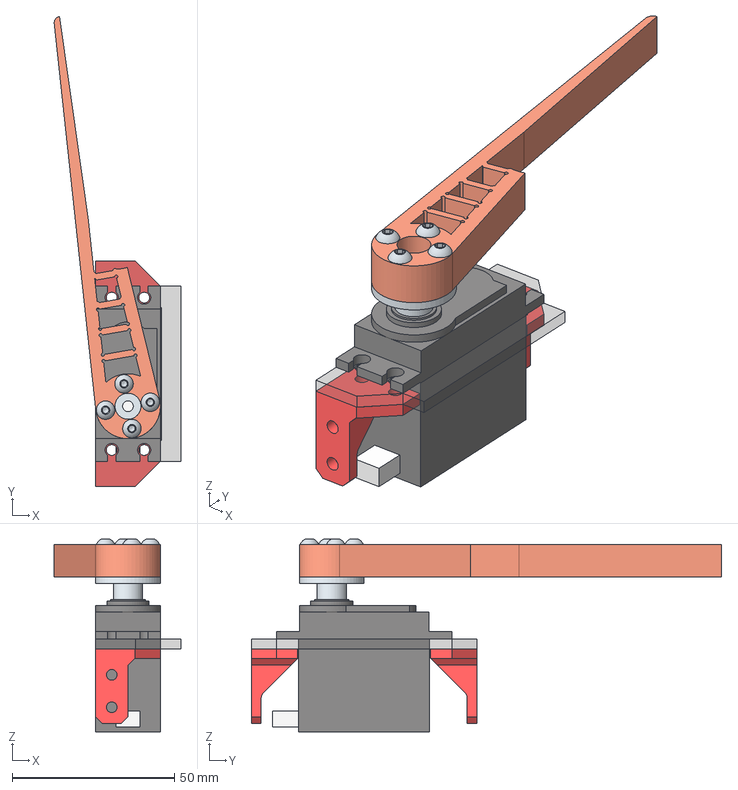
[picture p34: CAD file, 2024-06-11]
project/Robot_principal_model3D/Ass Act panneau solaire G.step
39.1 x 144.9 x 59.5 mm
support servo 2
Palonnier rond
Socket button head screw M3x0.5 x 12 x 4
Actionneur panneau solaire
support servo1
Cadre Gauche

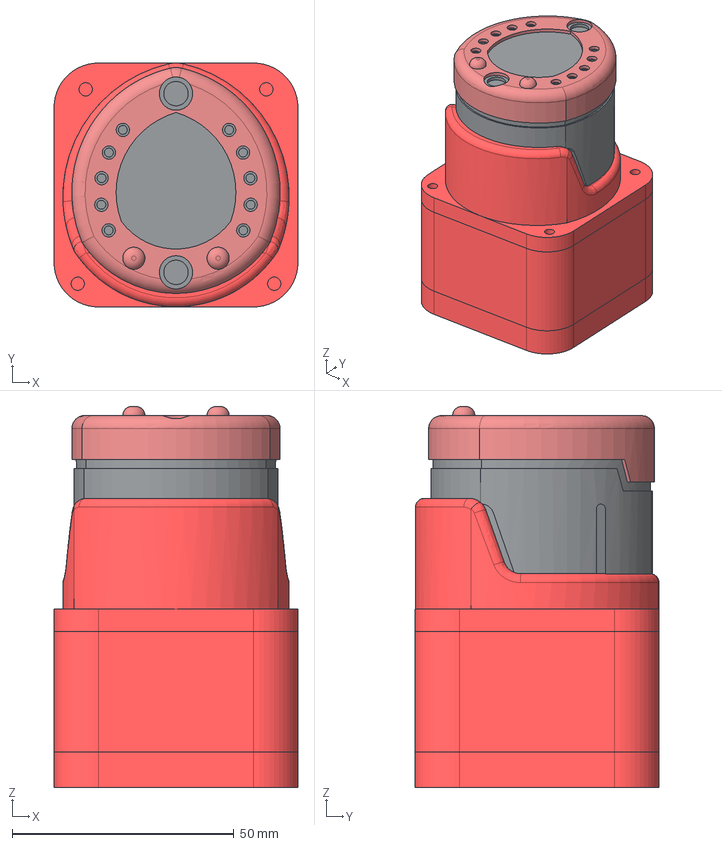
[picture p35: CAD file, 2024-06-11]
project/Robot_principal_model3D/Support batterie et batterie.step
55.0 x 55.0 x 85.9 mm
cul-b
Top-support-b
Batterie
Millieu-support-b

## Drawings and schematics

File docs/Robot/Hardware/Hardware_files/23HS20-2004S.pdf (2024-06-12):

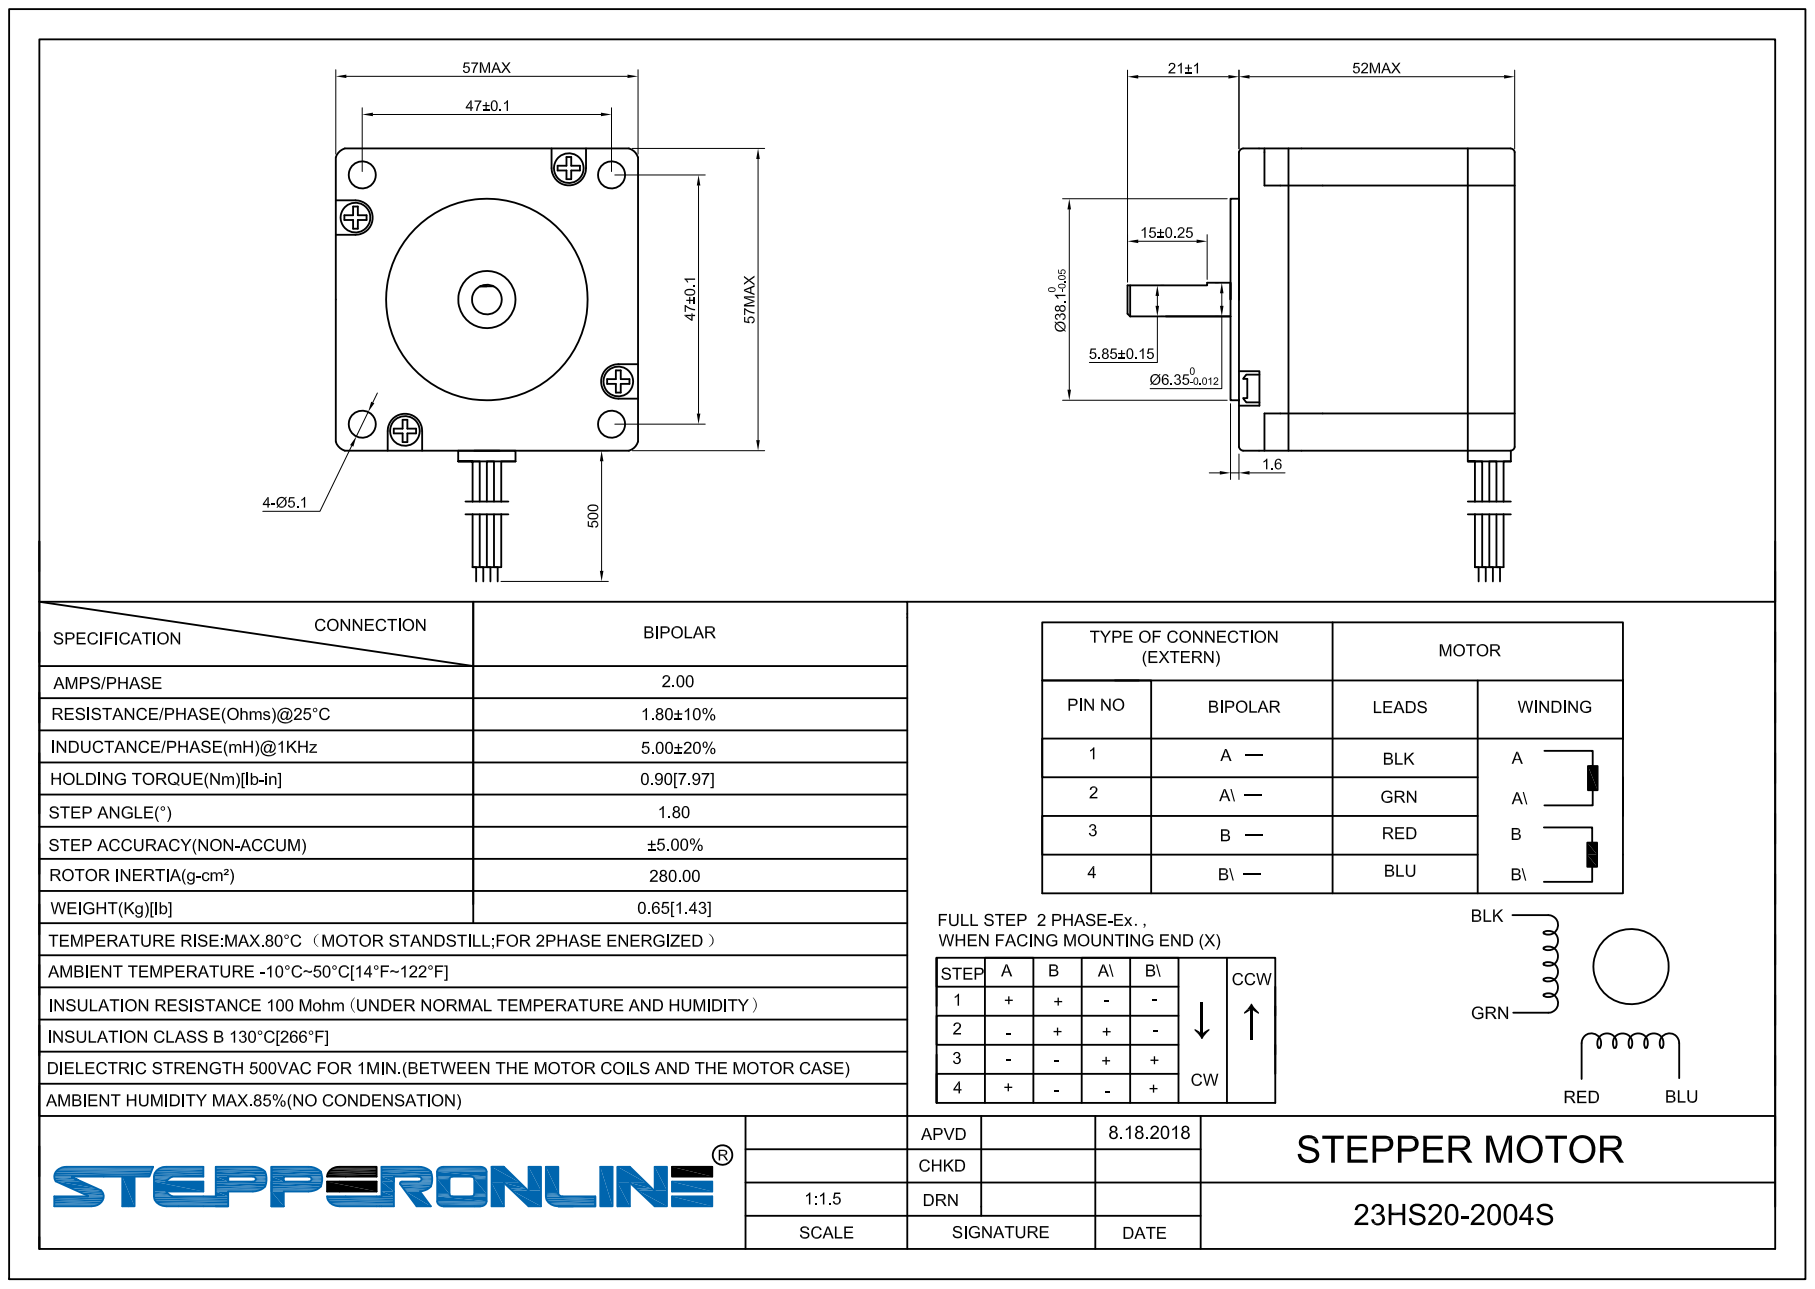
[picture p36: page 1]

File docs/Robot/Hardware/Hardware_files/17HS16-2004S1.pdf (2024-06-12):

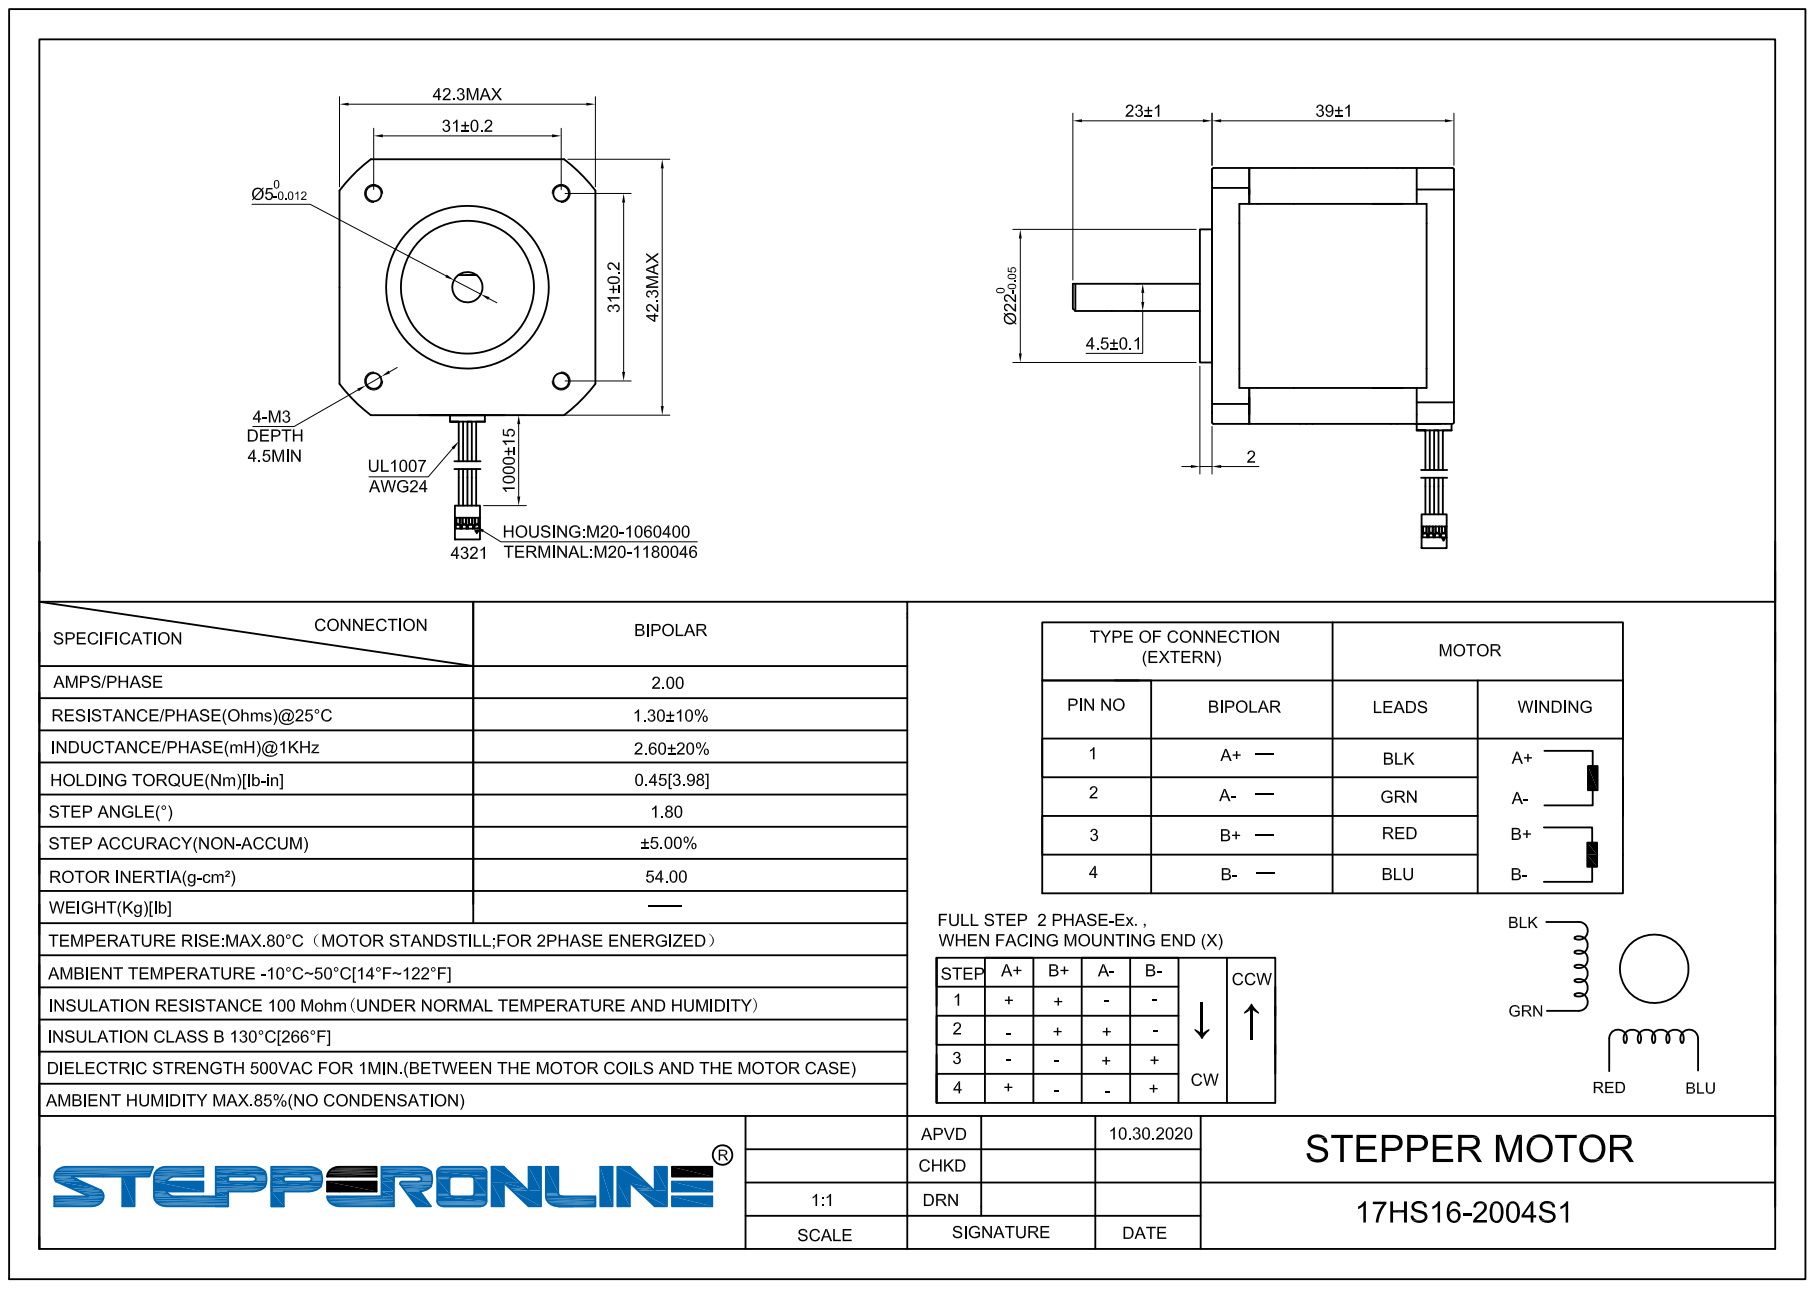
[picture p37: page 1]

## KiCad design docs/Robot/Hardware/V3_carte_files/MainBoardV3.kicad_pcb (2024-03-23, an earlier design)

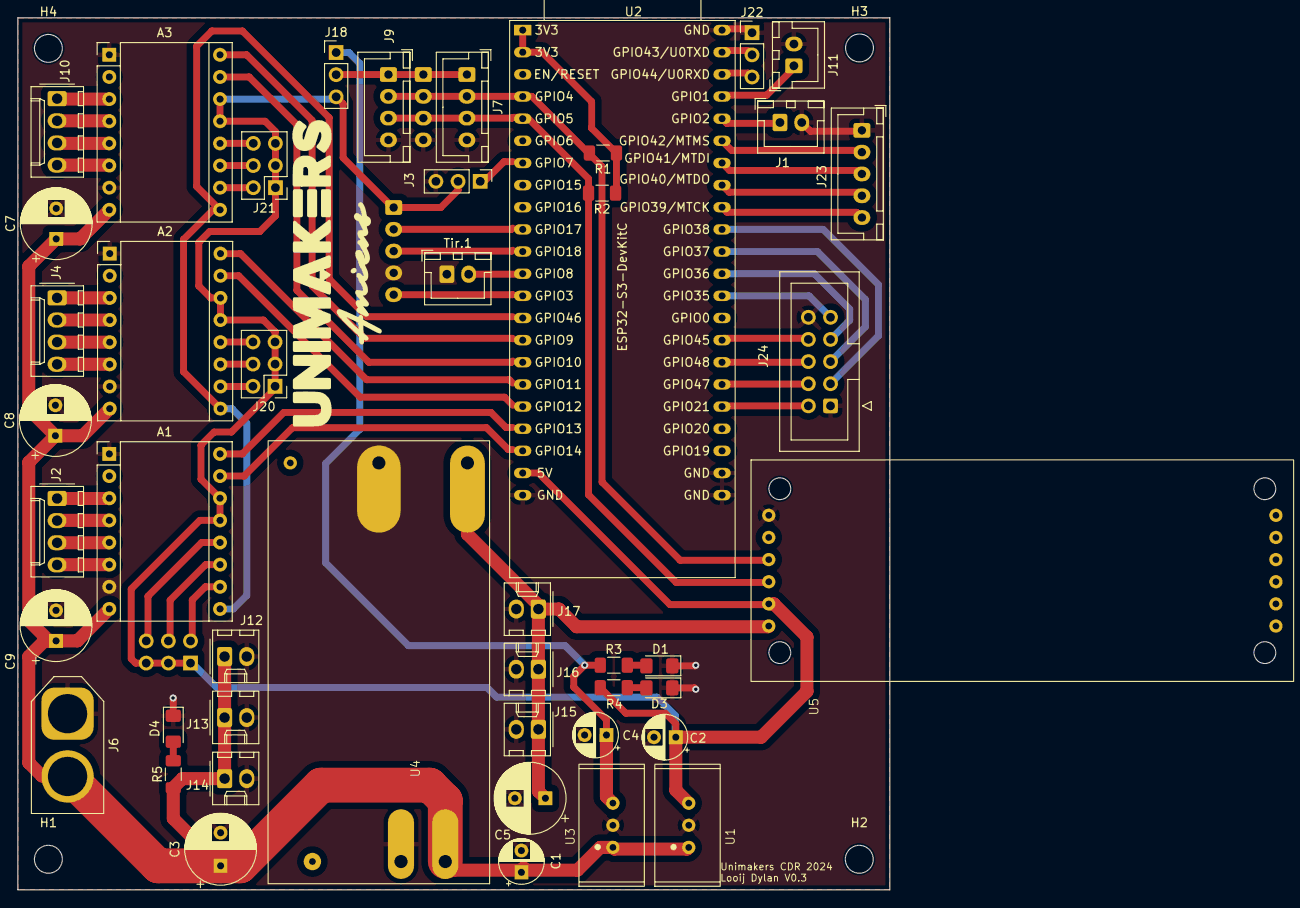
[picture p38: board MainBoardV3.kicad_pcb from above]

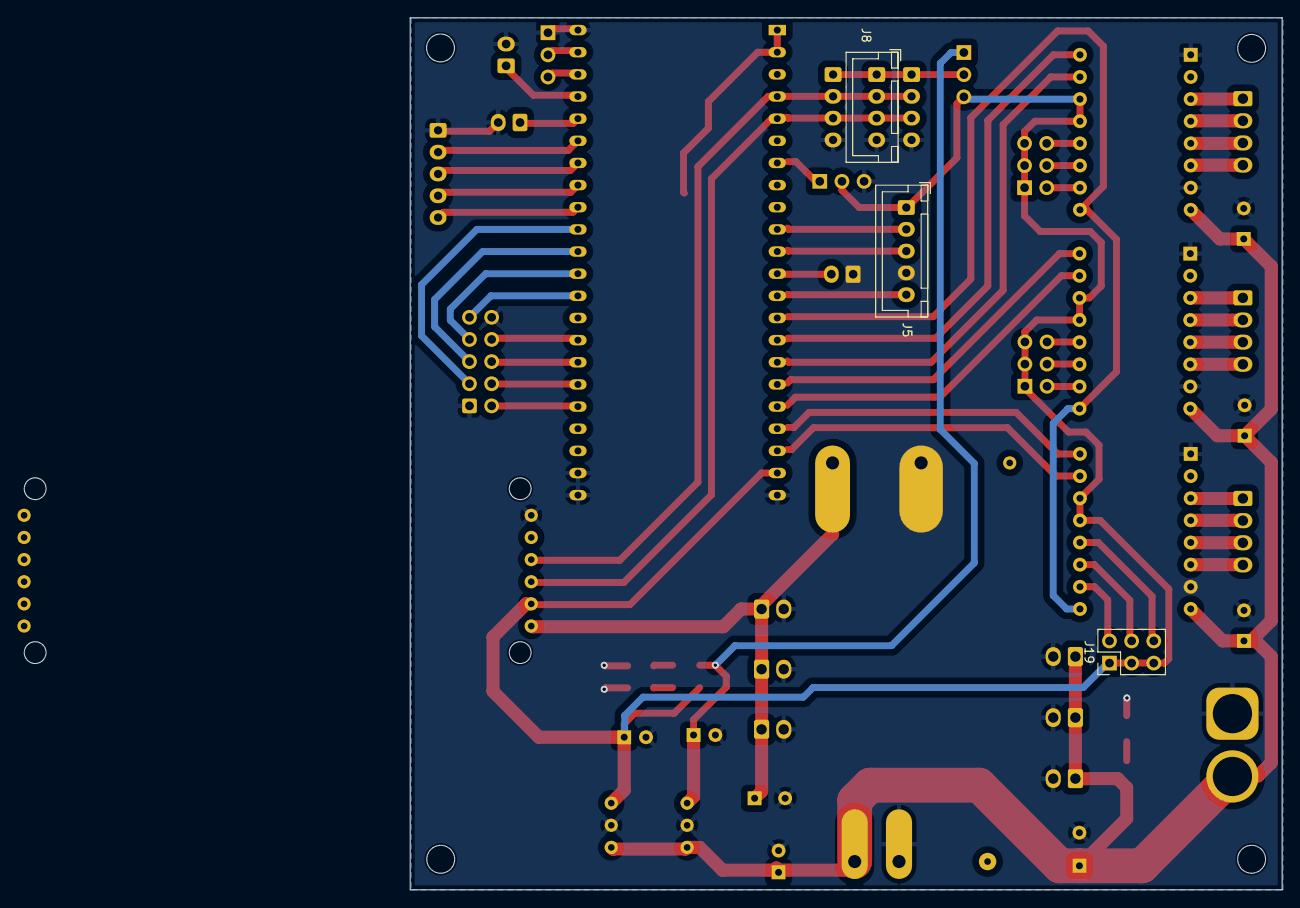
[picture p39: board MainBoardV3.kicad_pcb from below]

Board: 2 copper layers, 100.0 x 100.0 mm, 53 parts (3 on the bottom side), 61 nets.

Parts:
A1, A2, A3: Pololu_Breakout_DRV8825; Pololu_Breakout-16_15.2x20.3mm
C1, C2, C4: C_Polarized; CP_Radial_D5.0mm_P2.50mm
C3: C_Polarized; CP_Radial_D8.0mm_P3.80mm
C5, C7, C8, C9: C_Polarized; CP_Radial_D8.0mm_P3.50mm
D1, D3, D4: LED_Small; LED_1206_3216Metric_Pad1.42x1.75mm_HandSolder
H1, H2, H3, H4: MountingHole; MountingHole_3.2mm_M3
J1, J11: Conn_01x02; JST_XH_B2B-XH-A_1x02_P2.50mm_Vertical
J2, J4, J10: Conn_01x04; Molex_KK-254_AE-6410-04A_1x04_P2.54mm_Vertical
J3, J18, J22: Conn_01x03; PinHeader_1x03_P2.54mm_Vertical
J5, J23: Conn_01x05; JST_XH_B5B-XH-A_1x05_P2.50mm_Vertical
J6: Conn_01x02; AMASS_XT60-M_1x02_P7.20mm_Vertical
J7, J8, J9: Conn_01x04; JST_XH_B4B-XH-A_1x04_P2.50mm_Vertical
J12, J13, J14, J15, J16, J17: Conn_01x02; Molex_KK-254_AE-6410-02A_1x02_P2.54mm_Vertical
J19, J20, J21: Conn_02x03_Odd_Even; PinHeader_2x03_P2.54mm_Vertical
J24: Conn_02x05_Odd_Even; IDC-Header_2x05_P2.54mm_Vertical
R1, R2: R; R_1206_3216Metric_Pad1.30x1.75mm_HandSolder
R3, R4, R5: R_Small; R_1206_3216Metric_Pad1.30x1.75mm_HandSolder
Tir.1: Conn_01x02; JST_XH_B2B-XH-A_1x02_P2.50mm_Vertical
U1: TSR_2-2450; Traco 2- 24xx
U2: ESP32-S3-DevKitC
U3: TSR_2-2433; Traco 2- 24xx
U4: TEN_50-2411WI; Traco TEN 50 series
U5: PCA9685breakout

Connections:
+3.3V: R1.1, R2.1, U2.1 (3V3), U2.2 (3V3)
+3.3VP: C4.1, J18.1, R3.1, U3.3 (VO)
+5V: A1.13 (~RST), A1.14 (~SLP), A2.13 (~RST), A2.14 (~SLP), A3.13 (~RST), A3.14 (~SLP), C2.1, J3.2, J5.1, J18.3, J19.1, J19.3, J19.5, J20.1, J20.3, J20.5, J21.1, J21.3, J21.5, R4.1, U1.3 (VO), U2.21 (5V), U5.4 (VCC)
+5VP: C5.1, J15.1, J16.1, J17.1, U4.4 (+Vout), U5.5 (V+_6VMax)
+12V: A1.8 (VMOT), A2.8 (VMOT), A3.8 (VMOT), C1.1, C3.1, C7.1, C8.1, C9.1, J6.2, J12.1, J13.1, J14.1, R5.1, U1.1 (VI), U3.1 (VI), U4.1 (+Vin)
/GP1: J11.1, U2.41 (GPIO1/ADC1_CH0)
/GP2: J1.1, U2.40 (GPIO2/ADC1_CH1)
DIR1: A1.16 (DIR), U2.19 (GPIO13/ADC2_CH2)
DIR2: A2.16 (DIR), U2.17 (GPIO11/ADC2_CH0)
DIR3: A3.16 (DIR), U2.15 (GPIO9/ADC1_CH8)
EN: A1.9 (~EN), A2.9 (~EN), A3.9 (~EN), U2.14 (GPIO46)
GND: A1.1 (GND), A1.7 (GND), A2.1 (GND), A2.7 (GND), A3.1 (GND), A3.7 (GND), C1.2, C2.2, C3.2, C4.2, C5.2, C7.2, C8.2, C9.2, D1.1 (K), D3.1 (K), D4.1 (K), J1.2, J3.3, J5.4, J6.1, J7.4, J8.4, J9.4, J11.2, J12.2, J13.2, J14.2, J15.2, J16.2, J17.2, J22.1, J23.1, J24.1, J24.10, Tir.1.1, U1.2 (GND), U2.22 (GND), U2.23 (GND), U2.24 (GND), U2.44 (GND), U3.2 (GND), U4.2 (-Vin), U4.5 (-Vout), U5.0 (GND)
GPI035: J24.9, U2.32 (GPIO35)
GPIO21: J24.2, U2.27 (GPIO21)
GPIO36: J24.7, U2.33 (GPIO36)
GPIO37: J24.5, U2.34 (GPIO37)
GPIO38: J24.3, U2.35 (GPIO38)
GPIO45: J24.8, U2.30 (GPIO45)
GPIO47: J24.4, U2.28 (GPIO47)
GPIO48: J24.6, U2.29 (GPIO48)
LIDARRX: J5.2, U2.10 (GPIO17/ADC2_CH6)
LIDARTX: J5.3, U2.11 (GPIO18/ADC2_CH7)
Neopixel: J3.1, U2.7 (GPIO7/ADC1_CH6)
unnamed: A1.4 (A1), J2.2
unnamed: A1.3 (A2), J2.1
unnamed: A1.5 (B1), J2.3
unnamed: A1.6 (B2), J2.4
unnamed: A1.10 (M0), J19.2
unnamed: A1.11 (M1), J19.4
unnamed: A1.12 (M2), J19.6
unnamed: A2.4 (A1), J4.2
unnamed: A2.3 (A2), J4.1
unnamed: A2.5 (B1), J4.3
unnamed: A2.6 (B2), J4.4
unnamed: A2.10 (M0), J20.2
unnamed: A2.11 (M1), J20.4
unnamed: A2.12 (M2), J20.6
unnamed: A3.4 (A1), J10.2
unnamed: A3.3 (A2), J10.1
unnamed: A3.5 (B1), J10.3
unnamed: A3.6 (B2), J10.4
unnamed: A3.10 (M0), J21.2
unnamed: A3.11 (M1), J21.4
unnamed: A3.12 (M2), J21.6
unnamed: D1.2 (A), R3.2
unnamed: D3.2 (A), R4.2
unnamed: D4.2 (A), R5.2
unnamed: J7.1, J8.1, J9.1, J18.2
unnamed: J22.2, U2.43 (GPIO43/U0TXD)
unnamed: J22.3, U2.42 (GPIO44/U0RXD)
unnamed: J23.2, U2.39 (GPIO42/MTMS)
unnamed: J23.3, U2.38 (GPIO41/MTDI)
unnamed: J23.4, U2.37 (GPIO40/MTDO)
unnamed: J23.5, U2.36 (GPIO39/MTCK)
unnamed: Tir.1.2, U2.12 (GPIO8/ADC1_CH7)
PWMLIDAR: J5.5, U2.13 (GPIO3/ADC1_CH2)
SCL: J7.2, J8.2, J9.2, R1.2, U2.4 (GPIO4/ADC1_CH3), U5.2 (SCL)
SDA: J7.3, J8.3, J9.3, R2.2, U2.5 (GPIO5/ADC1_CH4), U5.3 (SDA)
STEP1: A1.15 (STEP), U2.20 (GPIO14/ADC2_CH3)
STEP2: A2.15 (STEP), U2.18 (GPIO12/ADC2_CH1)
STEP3: A3.15 (STEP), U2.16 (GPIO10/ADC1_CH9)

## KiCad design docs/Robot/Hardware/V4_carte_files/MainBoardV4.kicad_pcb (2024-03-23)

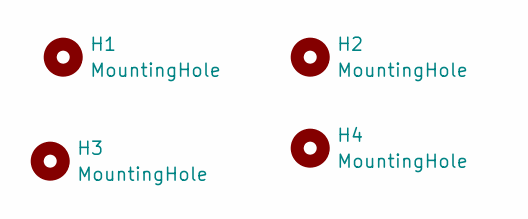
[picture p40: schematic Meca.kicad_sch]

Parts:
H1, H2, H3, H4: MountingHole; MountingHole_3.2mm_M3

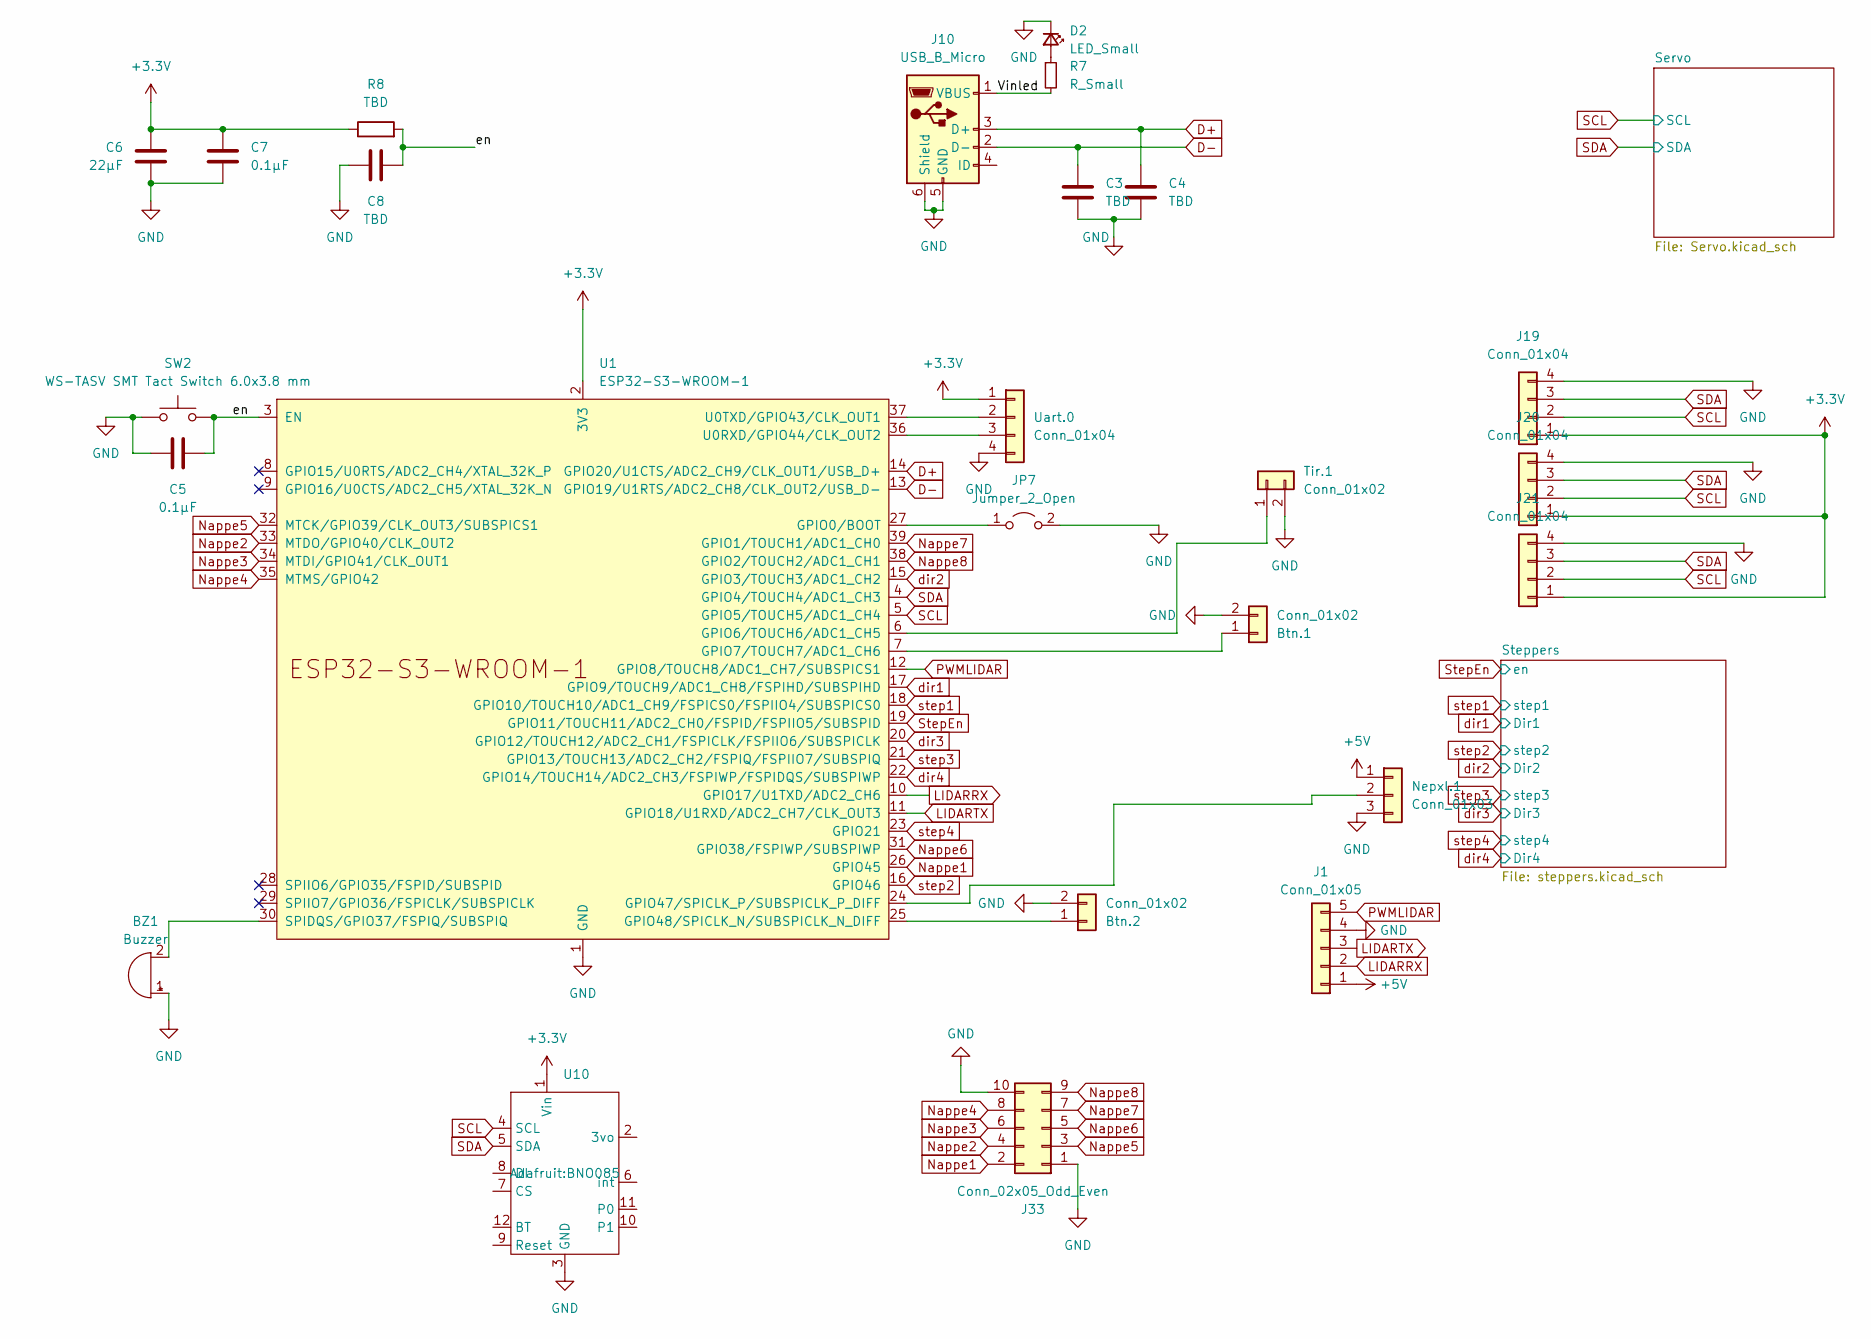
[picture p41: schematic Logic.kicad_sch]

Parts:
BZ1: Buzzer; Buzzer_12x9.5RM7.6
Btn.1, Btn.2: Conn_01x02; JST_XH_B2B-XH-A_1x02_P2.50mm_Vertical
C3, C4, C8: TBD; C_0805_2012Metric_Pad1.18x1.45mm_HandSolder
C5, C7: 0.1µF; C_0805_2012Metric_Pad1.18x1.45mm_HandSolder
C6: 22µF; C_0805_2012Metric_Pad1.18x1.45mm_HandSolder
D2: LED_Small; LED_1206_3216Metric_Pad1.42x1.75mm_HandSolder
J1: Conn_01x05; JST_XH_B5B-XH-A_1x05_P2.50mm_Vertical
J10: USB_B_Micro; USB_Micro-B_Wuerth_629105150521
J19, J20, J21: Conn_01x04; JST_XH_B4B-XH-A_1x04_P2.50mm_Vertical
J33: Conn_02x05_Odd_Even; IDC-Header_2x05_P2.54mm_Vertical
JP7: Jumper_2_Open; PinHeader_1x02_P2.54mm_Vertical
Nepxl.1: Conn_01x03; PinSocket_1x03_P2.54mm_Vertical
R7: R_Small; R_1206_3216Metric_Pad1.30x1.75mm_HandSolder
R8: TBD; R_1206_3216Metric_Pad1.30x1.75mm_HandSolder
SW2: WS-TASV SMT Tact Switch 6.0x3.8 mm; WS-TASV SMT Tact Switch
Tir.1: Conn_01x02; JST_XH_B2B-XH-A_1x02_P2.50mm_Vertical
U1: ESP32-S3-WROOM-1
U10: BNO085
Uart.0: Conn_01x04; JST_XH_B4B-XH-A_1x04_P2.50mm_Vertical

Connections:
+3.3V: C6.2, C7.2, J19.1, J20.1, J21.1, R8.1, U1.2 (3V3), U10.1 (Vin), Uart.0.1; also elsewhere on the board
+5V: J1.1, Nepxl.1.1; also elsewhere on the board
/Logic/Vinled: J10.1 (VBUS), R7.2
/Logic/en: C5.2, C8.1, R8.2, SW2.2, U1.3 (EN)
D+: C4.1, J10.3 (D+), U1.14 (GPIO20/U1CTS/ADC2_CH9/CLK_OUT1/USB_D+)
D-: C3.1, J10.2 (D-), U1.13 (GPIO19/U1RTS/ADC2_CH8/CLK_OUT2/USB_D-)
GND: BZ1.1 (-), Btn.1.2, Btn.2.2, C3.2, C4.2, C5.1, C6.1, C7.1, C8.2, D2.1 (K), J1.4, J10.5 (GND), J10.6 (Shield), J19.4, J20.4, J21.4, J33.1, J33.10, JP7.2 (B), Nepxl.1.3, SW2.1, Tir.1.2, U1.1 (GND), U1.40 (GND), U1.41 (GND), U10.3 (GND), Uart.0.4; also elsewhere on the board
LIDARRX: J1.2, U1.10 (GPIO17/U1TXD/ADC2_CH6)
LIDARTX: J1.3, U1.11 (GPIO18/U1RXD/ADC2_CH7/CLK_OUT3)
Nappe1: J33.2, U1.26 (GPIO45)
Nappe2: J33.4, U1.33 (MTDO/GPIO40/CLK_OUT2)
Nappe3: J33.6, U1.34 (MTDI/GPIO41/CLK_OUT1)
Nappe4: J33.8, U1.35 (MTMS/GPIO42)
Nappe5: J33.3, U1.32 (MTCK/GPIO39/CLK_OUT3/SUBSPICS1)
Nappe6: J33.5, U1.31 (GPIO38/FSPIWP/SUBSPIWP)
Nappe7: J33.7, U1.39 (GPIO1/TOUCH1/ADC1_CH0)
Nappe8: J33.9, U1.38 (GPIO2/TOUCH2/ADC1_CH1)
unnamed: BZ1.2 (+), U1.30 (SPIDQS/GPIO37/FSPIQ/SUBSPIQ)
unnamed: Btn.1.1, U1.7 (GPIO7/TOUCH7/ADC1_CH6)
unnamed: Btn.2.1, U1.25 (GPIO48/SPICLK_N/SUBSPICLK_N_DIFF)
unnamed: D2.2 (A), R7.1
unnamed: JP7.1 (A), U1.27 (GPIO0/BOOT)
unnamed: Nepxl.1.2, U1.24 (GPIO47/SPICLK_P/SUBSPICLK_P_DIFF)
unnamed: Tir.1.1, U1.6 (GPIO6/TOUCH6/ADC1_CH5)
unnamed: U1.36 (U0RXD/GPIO44/CLK_OUT2), Uart.0.3
unnamed: U1.37 (U0TXD/GPIO43/CLK_OUT1), Uart.0.2
PWMLIDAR: J1.5, U1.12 (GPIO8/TOUCH8/ADC1_CH7/SUBSPICS1)
SCL: J19.2, J20.2, J21.2, U1.5 (GPIO5/TOUCH5/ADC1_CH4), U10.4 (SCL); also elsewhere on the board
SDA: J19.3, J20.3, J21.3, U1.4 (GPIO4/TOUCH4/ADC1_CH3), U10.5 (SDA); also elsewhere on the board
StepEn: U1.19 (GPIO11/TOUCH11/ADC2_CH0/FSPID/FSPIIO5/S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); also elsewhere on the board
dir1: U1.17 (GPIO9/TOUCH9/ADC1_CH8/FSPIHD/SUBSPIHD); also elsewhere on the board
dir2: U1.15 (GPIO3/TOUCH3/ADC1_CH2); also elsewhere on the board
dir3: U1.20 (GPIO12/TOUCH12/ADC2_CH1/FSPICLK/FSPIIO6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); also elsewhere on the board
dir4: U1.22 (GPIO14/TOUCH14/ADC2_CH3/FSPIWP/FSPIDQS/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); also elsewhere on the board
step1: U1.18 (GPIO10/TOUCH10/ADC1_CH9/FSPICS0/FSPIIO4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); also elsewhere on the board
step2: U1.16 (GPIO46); also elsewhere on the board
step3: U1.21 (GPIO13/TOUCH13/ADC2_CH2/FSPIQ/FSPIIO7/S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); also elsewhere on the board
step4: U1.23 (GPIO21); also elsewhere on the board

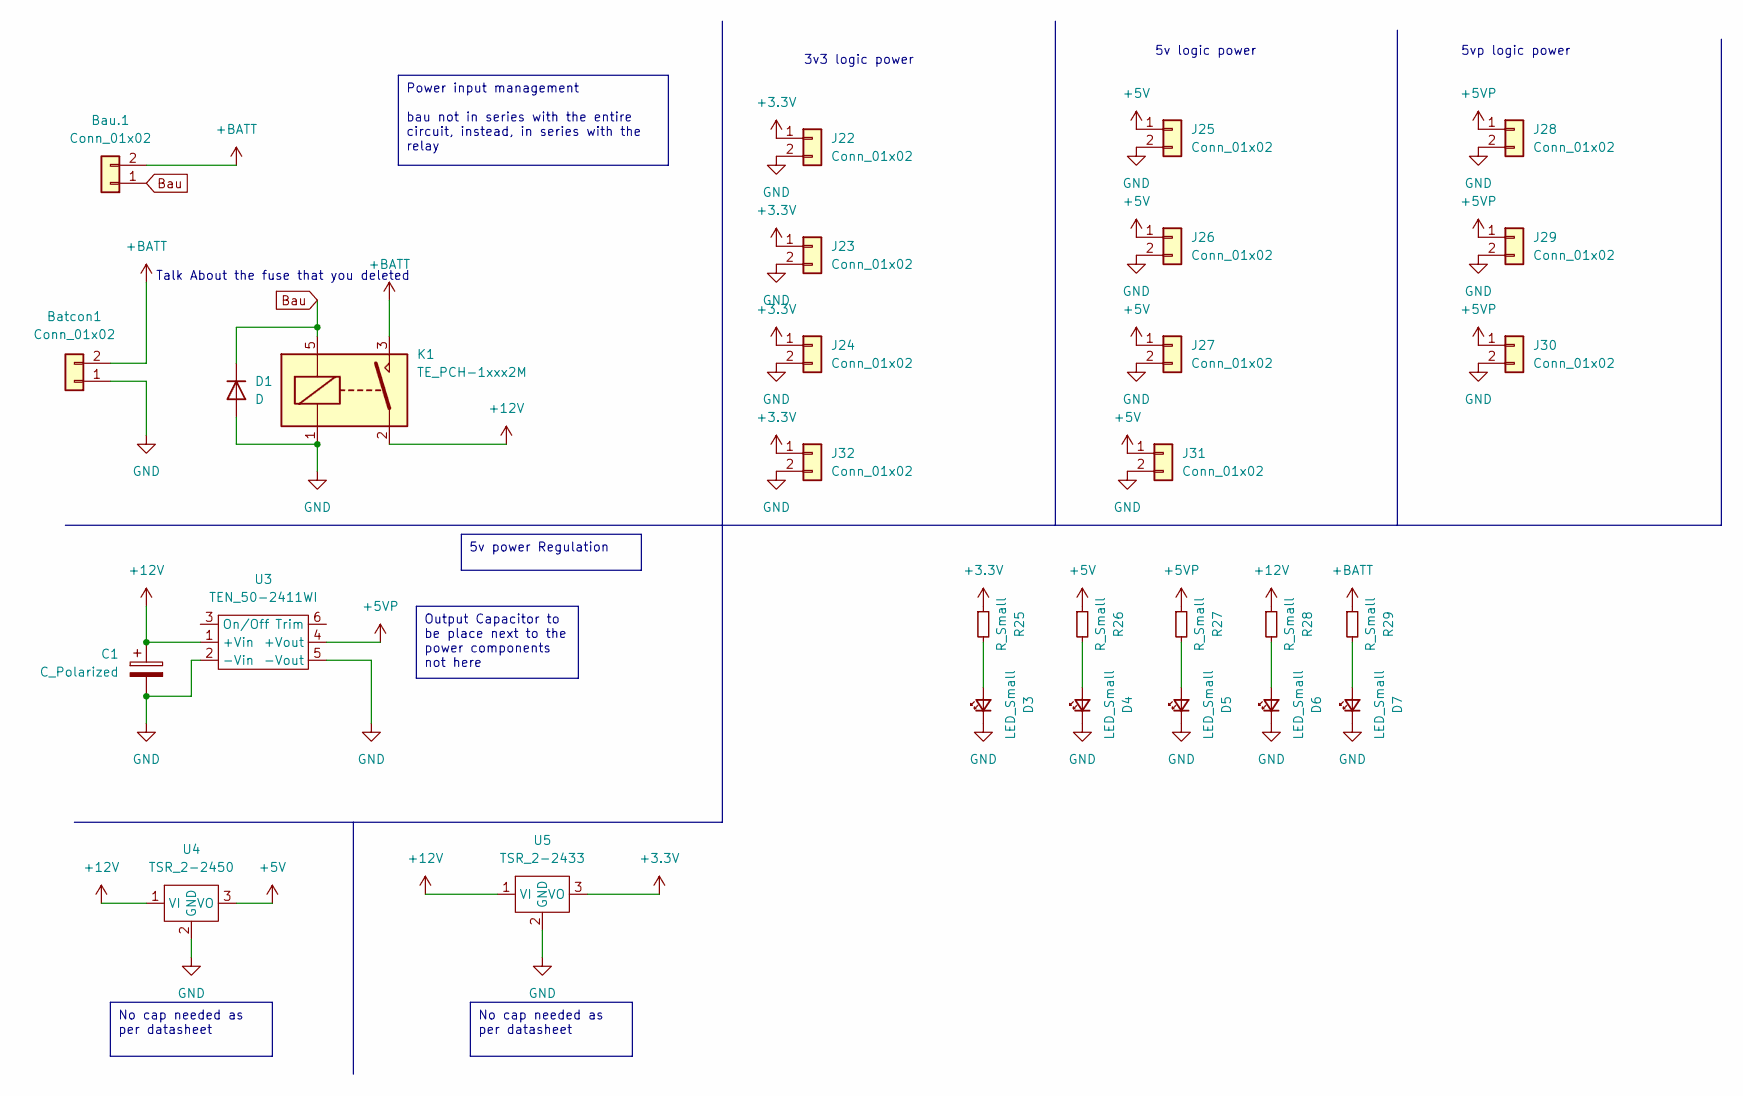
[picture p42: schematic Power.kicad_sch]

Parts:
Batcon1: Conn_01x02; AMASS_XT60-F_1x02_P7.20mm_Vertical
Bau.1: Conn_01x02; Molex_KK-254_AE-6410-02A_1x02_P2.54mm_Vertical
C1: C_Polarized
D1: D; D_DO-35_SOD27_P10.16mm_Horizontal
D3, D4, D5, D6, D7: LED_Small; LED_1206_3216Metric_Pad1.42x1.75mm_HandSolder
J22, J23, J24, J25, J26, J27, J28, J29, J30, J31, J32: Conn_01x02; Molex_KK-254_AE-6410-02A_1x02_P2.54mm_Vertical
K1: TE_PCH-1xxx2M; Relay_SPST_TE_PCH-1xxx2M
R25, R26, R27, R28, R29: R_Small; LED_1206_3216Metric_Pad1.42x1.75mm_HandSolder
U3: TEN_50-2411WI; Traco TEN 50 series
U4: TSR_2-2450; Traco 2- 24xx
U5: TSR_2-2433; Traco 2- 24xx

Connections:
+3.3V: J22.1, J23.1, J24.1, J32.1, R25.1, U5.3 (VO); also elsewhere on the board
+5V: J25.1, J26.1, J27.1, J31.1, R26.1, U4.3 (VO); also elsewhere on the board
+5VP: J28.1, J29.1, J30.1, R27.1, U3.4 (+Vout); also elsewhere on the board
+12V: C1.1, K1.2, R28.1, U3.1 (+Vin), U4.1 (VI), U5.1 (VI); also elsewhere on the board
+BATT: Batcon1.2, Bau.1.2, K1.3, R29.1
Bau: Bau.1.1, D1.1 (K), K1.5
GND: Batcon1.1, C1.2, D1.2 (A), D3.1 (K), D4.1 (K), D5.1 (K), D6.1 (K), D7.1 (K), J22.2, J23.2, J24.2, J25.2, J26.2, J27.2, J28.2, J29.2, J30.2, J31.2, J32.2, K1.1, U3.2 (-Vin), U3.5 (-Vout), U4.2 (GND), U5.2 (GND); also elsewhere on the board
unnamed: D3.2 (A), R25.2
unnamed: D4.2 (A), R26.2
unnamed: D5.2 (A), R27.2
unnamed: D6.2 (A), R28.2
unnamed: D7.2 (A), R29.2

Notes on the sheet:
Output Capacitor to be place next to the power components not here
5v power Regulation
No cap needed as per datasheet
Power input management bau not in series with the entire circuit, instead, in series with the relay
5vp logic power
Talk About the fuse that you deleted
5v logic power
3v3 logic power

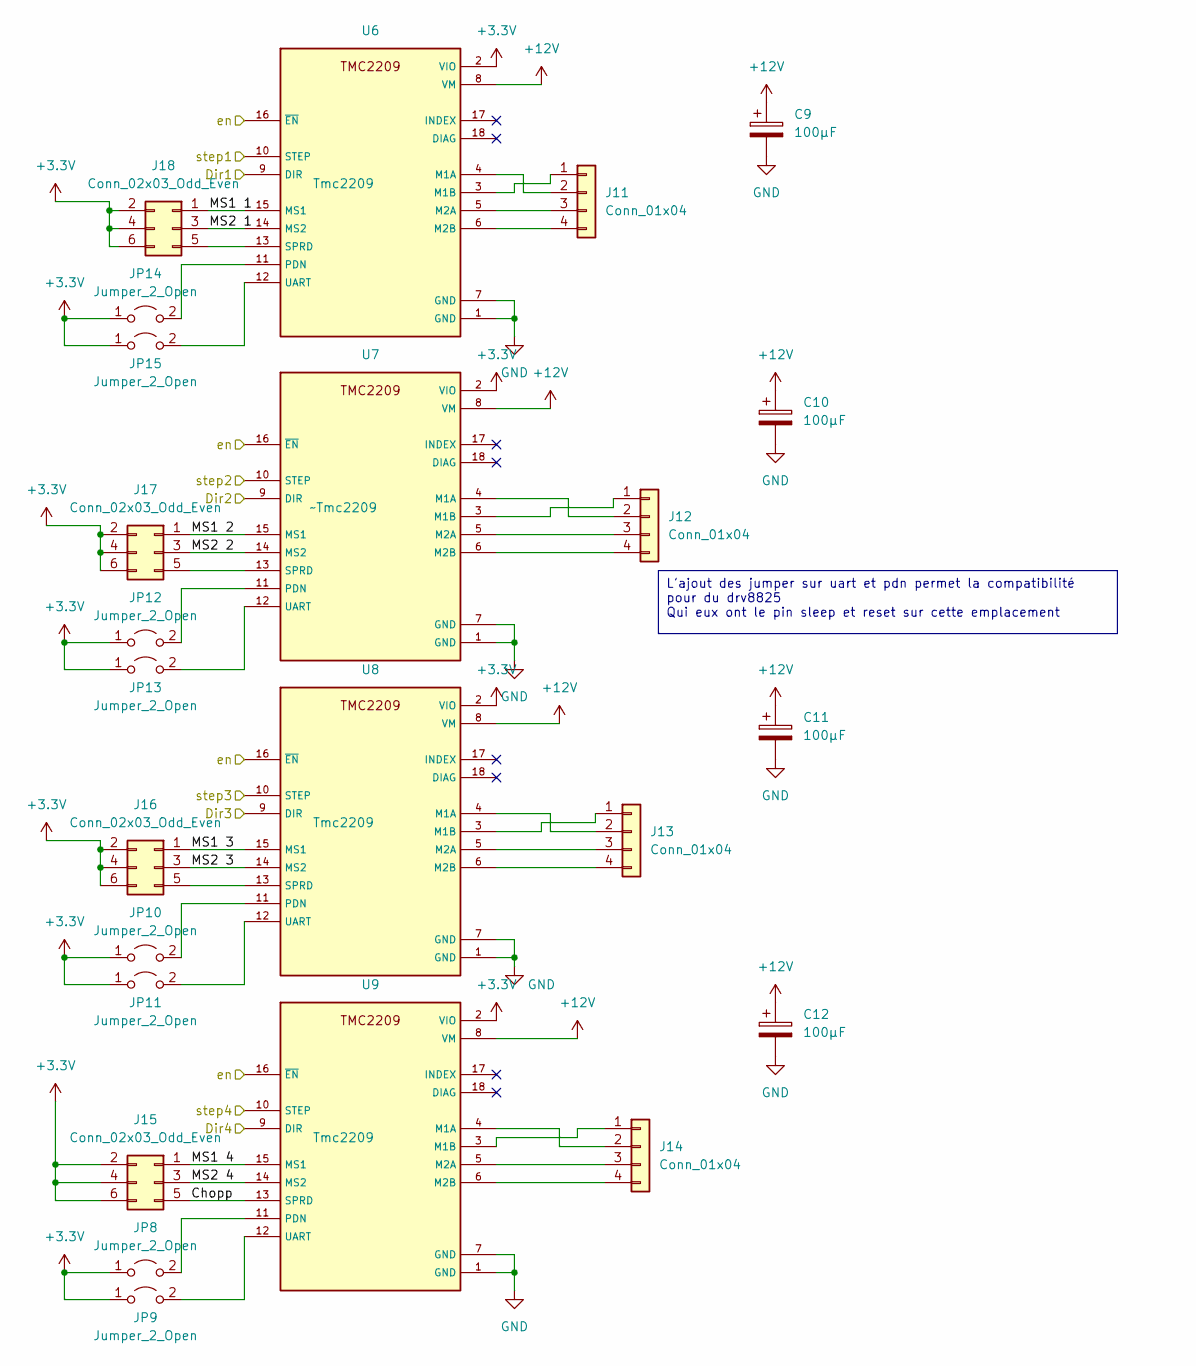
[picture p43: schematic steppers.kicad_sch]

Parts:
C9, C10, C11, C12: 100µF; CP_Elec_10x10.5
J11, J12, J13, J14: Conn_01x04; Molex_KK-254_AE-6410-04A_1x04_P2.54mm_Vertical
J15, J16, J17, J18: Conn_02x03_Odd_Even; PinHeader_2x03_P2.54mm_Vertical
JP8, JP9, JP10, JP11, JP12, JP13, JP14, JP15: Jumper_2_Open; SolderJumper-2_P1.3mm_Open_Pad1.0x1.5mm
U6, U8, U9: Tmc2209; BOB_TMC2209_SILENTSTEPSTICK
U7: ~Tmc2209; BOB_TMC2209_SILENTSTEPSTICK

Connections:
+3.3V: J15.2, J15.4, J15.6, J16.2, J16.4, J16.6, J17.2, J17.4, J17.6, J18.2, J18.4, J18.6, JP8.1 (A), JP9.1 (A), JP10.1 (A), JP11.1 (A), JP12.1 (A), JP13.1 (A), JP14.1 (A), JP15.1 (A), U6.2 (VIO), U7.2 (VIO), U8.2 (VIO), U9.2 (VIO); also elsewhere on the board
+12V: C9.1, C10.1, C11.1, C12.1, U6.8 (VM), U7.8 (VM), U8.8 (VM), U9.8 (VM); also elsewhere on the board
/Logic/Steppers/Chopp: J15.5, U9.13 (SPRD)
/Logic/Steppers/MS1 1: J18.1, U6.15 (MS1)
/Logic/Steppers/MS1 2: J17.1, U7.15 (MS1)
/Logic/Steppers/MS1 3: J16.1, U8.15 (MS1)
/Logic/Steppers/MS1 4: J15.1, U9.15 (MS1)
/Logic/Steppers/MS2 1: J18.3, U6.14 (MS2)
/Logic/Steppers/MS2 2: J17.3, U7.14 (MS2)
/Logic/Steppers/MS2 3: J16.3, U8.14 (MS2)
/Logic/Steppers/MS2 4: J15.3, U9.14 (MS2)
GND: C9.2, C10.2, C11.2, C12.2, U6.1 (GND), U6.7 (GND), U7.1 (GND), U7.7 (GND), U8.1 (GND), U8.7 (GND), U9.1 (GND), U9.7 (GND); also elsewhere on the board
unnamed: J11.1, U6.3 (M1B)
unnamed: J11.2, U6.4 (M1A)
unnamed: J11.3, U6.5 (M2A)
unnamed: J11.4, U6.6 (M2B)
unnamed: J12.1, U7.3 (M1B)
unnamed: J12.2, U7.4 (M1A)
unnamed: J12.3, U7.5 (M2A)
unnamed: J12.4, U7.6 (M2B)
unnamed: J13.1, U8.3 (M1B)
unnamed: J13.2, U8.4 (M1A)
unnamed: J13.3, U8.5 (M2A)
unnamed: J13.4, U8.6 (M2B)
unnamed: J14.1, U9.3 (M1B)
unnamed: J14.2, U9.4 (M1A)
unnamed: J14.3, U9.5 (M2A)
unnamed: J14.4, U9.6 (M2B)
unnamed: J16.5, U8.13 (SPRD)
unnamed: J17.5, U7.13 (SPRD)
unnamed: J18.5, U6.13 (SPRD)
unnamed: JP8.2 (B), U9.11 (PDN)
unnamed: JP9.2 (B), U9.12 (UART)
unnamed: JP10.2 (B), U8.11 (PDN)
unnamed: JP11.2 (B), U8.12 (UART)
unnamed: JP12.2 (B), U7.11 (PDN)
unnamed: JP13.2 (B), U7.12 (UART)
unnamed: JP14.2 (B), U6.11 (PDN)
unnamed: JP15.2 (B), U6.12 (UART)
StepEn: U6.16 (~EN), U7.16 (~EN), U8.16 (~EN), U9.16 (~EN); also elsewhere on the board
dir1: U6.9 (DIR); also elsewhere on the board
dir2: U7.9 (DIR); also elsewhere on the board
dir3: U8.9 (DIR); also elsewhere on the board
dir4: U9.9 (DIR); also elsewhere on the board
step1: U6.10 (STEP); also elsewhere on the board
step2: U7.10 (STEP); also elsewhere on the board
step3: U8.10 (STEP); also elsewhere on the board
step4: U9.10 (STEP); also elsewhere on the board

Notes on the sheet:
L'ajout des jumper sur uart et pdn permet la compatibilité pour du drv8825 Qui eux ont le pin sleep et reset sur cette emplacement

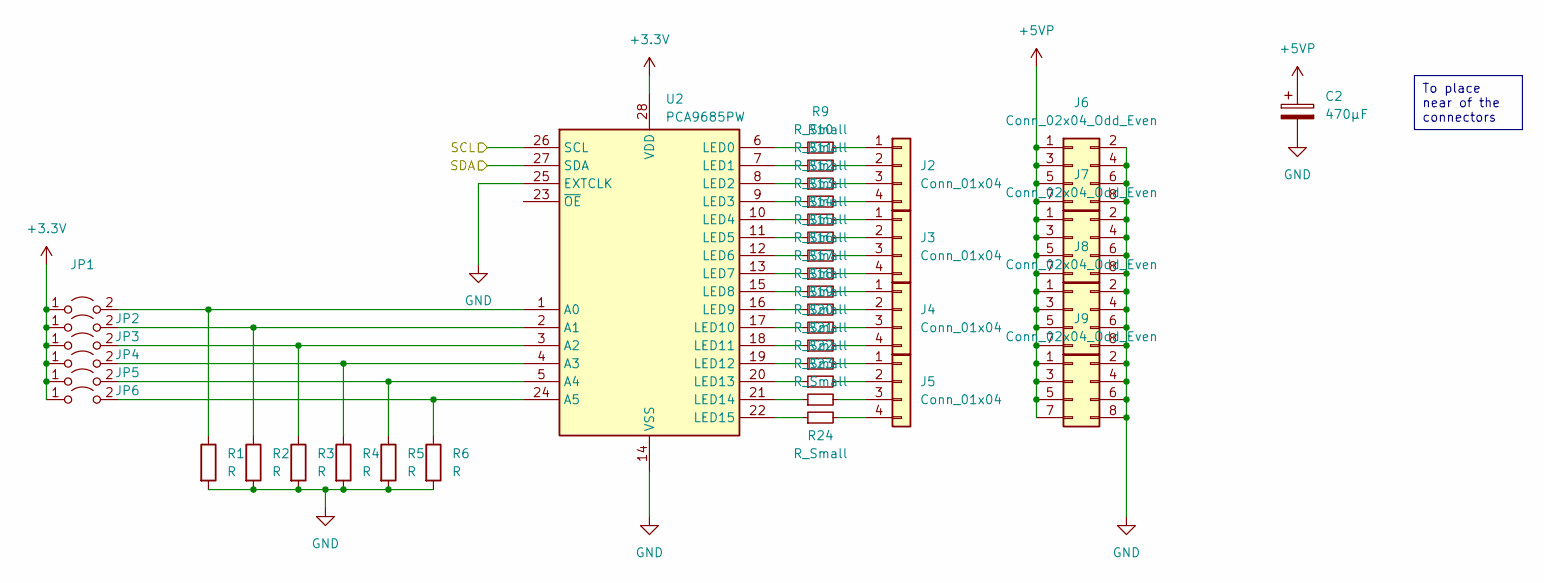
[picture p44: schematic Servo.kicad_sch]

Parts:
C2: 470µF; CP_Elec_10x10.5
J2, J3, J4, J5: Conn_01x04; PinHeader_1x04_P2.54mm_Vertical
J6, J7, J8, J9: Conn_02x04_Odd_Even; PinHeader_2x04_P2.54mm_Vertical
JP1, JP2, JP3, JP4, JP5, JP6: Jumper_2_Open; SolderJumper-2_P1.3mm_Open_Pad1.0x1.5mm
R1, R2, R3, R4, R5, R6: R; R_1206_3216Metric_Pad1.30x1.75mm_HandSolder
R9, R10, R11, R12, R13, R14, R15, R16, R17, R18, R19, R20, R21, R22, R23, R24: R_Small; R_1206_3216Metric_Pad1.30x1.75mm_HandSolder
U2: PCA9685PW; TSSOP-28_4.4x9.7mm_P0.65mm

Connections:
+3.3V: JP1.1 (A), JP2.1 (A), JP3.1 (A), JP4.1 (A), JP5.1 (A), JP6.1 (A), U2.28 (VDD); also elsewhere on the board
+5VP: C2.1, J6.1, J6.3, J6.5, J6.7, J7.1, J7.3, J7.5, J7.7, J8.1, J8.3, J8.5, J8.7, J9.1, J9.3, J9.5, J9.7; also elsewhere on the board
GND: C2.2, J6.2, J6.4, J6.6, J6.8, J7.2, J7.4, J7.6, J7.8, J8.2, J8.4, J8.6, J8.8, J9.2, J9.4, J9.6, J9.8, R1.2, R2.2, R3.2, R4.2, R5.2, R6.2, U2.14 (VSS), U2.25 (EXTCLK); also elsewhere on the board
unnamed: J2.1, R9.2
unnamed: J2.2, R10.2
unnamed: J2.3, R11.2
unnamed: J2.4, R12.2
unnamed: J3.1, R13.2
unnamed: J3.2, R14.2
unnamed: J3.3, R15.2
unnamed: J3.4, R16.2
unnamed: J4.1, R17.2
unnamed: J4.2, R18.2
unnamed: J4.3, R19.2
unnamed: J4.4, R20.2
unnamed: J5.1, R21.2
unnamed: J5.2, R22.2
unnamed: J5.3, R23.2
unnamed: J5.4, R24.2
unnamed: JP1.2 (B), R1.1, U2.1 (A0)
unnamed: JP2.2 (B), R2.1, U2.2 (A1)
unnamed: JP3.2 (B), R3.1, U2.3 (A2)
unnamed: JP4.2 (B), R4.1, U2.4 (A3)
unnamed: JP5.2 (B), R5.1, U2.5 (A4)
unnamed: JP6.2 (B), R6.1, U2.24 (A5)
unnamed: R9.1, U2.6 (LED0)
unnamed: R10.1, U2.7 (LED1)
unnamed: R11.1, U2.8 (LED2)
unnamed: R12.1, U2.9 (LED3)
unnamed: R13.1, U2.10 (LED4)
unnamed: R14.1, U2.11 (LED5)
unnamed: R15.1, U2.12 (LED6)
unnamed: R16.1, U2.13 (LED7)
unnamed: R17.1, U2.15 (LED8)
unnamed: R18.1, U2.16 (LED9)
unnamed: R19.1, U2.17 (LED10)
unnamed: R20.1, U2.18 (LED11)
unnamed: R21.1, U2.19 (LED12)
unnamed: R22.1, U2.20 (LED13)
unnamed: R23.1, U2.21 (LED14)
unnamed: R24.1, U2.22 (LED15)
SCL: U2.26 (SCL); also elsewhere on the board
SDA: U2.27 (SDA); also elsewhere on the board

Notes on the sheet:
To place near of the connectors

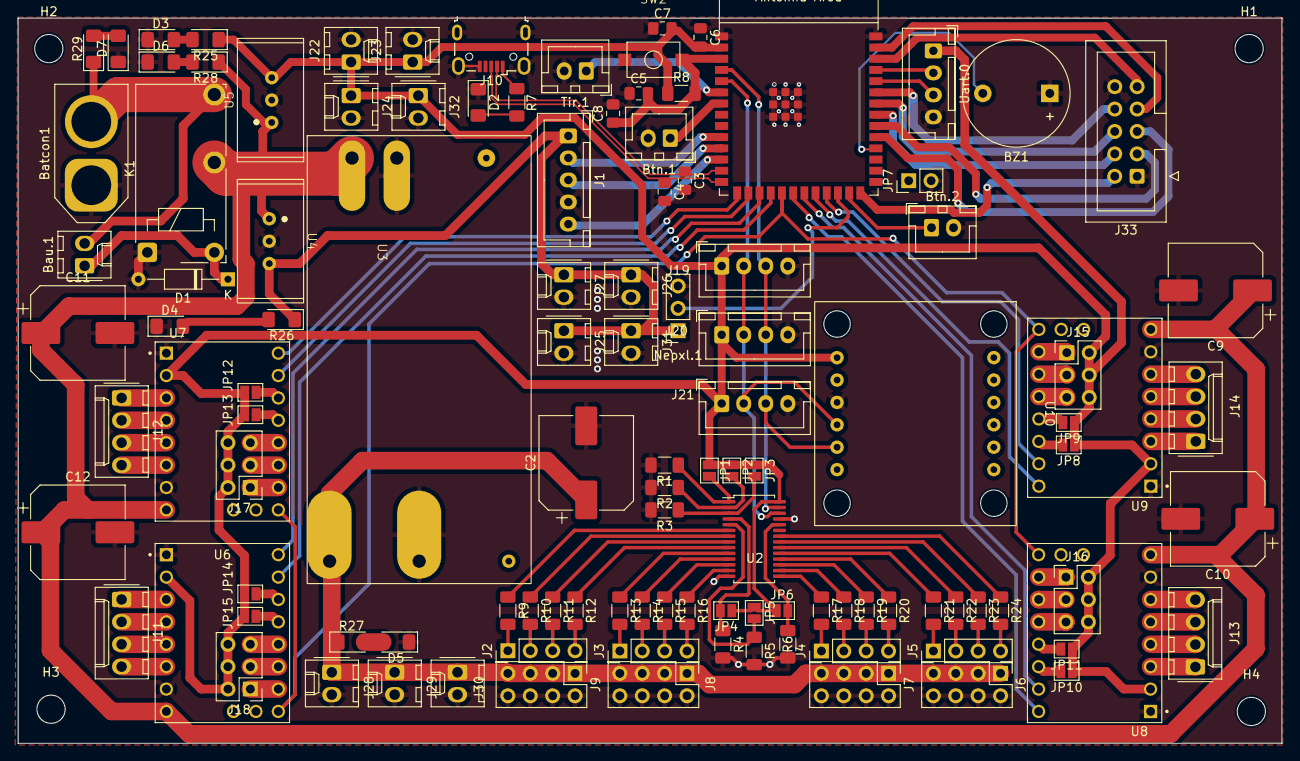
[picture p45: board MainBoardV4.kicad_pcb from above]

Board: 2 copper layers, 143.3 x 82.3 mm, 119 parts (0 on the bottom side), 121 nets.

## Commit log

2024-01-30 Update Mise en page, insertion Pami
2024-02-21 Ajout Visioneur Kicad
    [MainBoardV1.kicad_sch]
2024-02-27 Ajout du texte sur la pince, il manque encore les illustrations
2024-03-11 Add V2 carte + bug fix
    [MainBoardV2.kicad_sch]
2024-03-11 Add pcb
    [MainBoardV2.kicad_pcb]
2024-03-23 Enlévement des pages inutiles
2024-03-23 Rajout des 2 dernieres Cartes
    [MainBoardV4.kicad_pcb, MainBoardV4.kicad_sch, MainboardV3.kicad_pcb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]
2024-03-23 Bug fixes
    [Logic.kicad_sch, MainBoardV3.kicad_pcb, MainBoardV3.kicad_sch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]
2024-03-23 Ajout d'un page de réseaux avec post du projet uniquement
2024-03-27 init programmation_pamis
    Création du fichier markdown et écriture en partie de l'introduction
2024-03-27 Add files via upload
    ajout du vinyle pour le simulateur de stratégie
2024-03-27 rangement des fichiers
2024-03-31 ajout de la première partie du générateur de strategie
2024-04-02 modif ordre des pages
2024-04-02 modification des liens de p5.js et de p5.gui.js
2024-04-02 suppresion des /blob/main
2024-04-02 MaJ Documentation technique PCB PAMI
2024-04-04 modification de la source de mon fichier
2024-04-05 modif coordonées des points / ajout code sketch v2
2024-04-05 test avec code de adrien
2024-04-05 modif des liens
2024-04-05 ajout des fichiers de calcul de coordonées
2024-04-05 modif des includes
2024-04-05 sup de quelques boutons
2024-04-05 remaniement de la hierarchie des pages
2024-05-24 Create PCB_V1
2024-05-24 Ajouts des photo du robot
2024-05-25 change: steppers PAMI and things
2024-05-25 enregistrement des modifs
2024-05-26 fix: ultrasonic ref
2024-05-26 add: PAMI journée des projets video
2024-05-30 supression fichiez chassis a la demande de theo
2024-05-30 remove: invention de chatgpt sur la correction
2024-06-06 Reparation Kicad
2024-06-06 ajout video assemblage
2024-06-06 add: reste de pollinisation PAMI
2024-06-06 ajout des images/video de la pince, modifications du texte
2024-06-06 test changement de chemin
2024-06-06 loop video et ajout élément de jeu
2024-06-06 collage element de jeu
2024-06-06 test 4 reduire la taille des images
2024-06-07 chore: optimize jaw system with linear rail and servo motor
2024-06-07 add new carteristics PCB
2024-06-09 ajout de texte concernant le barillet
2024-06-10 changement de mise en forme
2024-06-10 fix name for the prototype N°2
2024-06-10 Correction des fautes d'orthographe par GPT
2024-06-11 Ajout lien OnShape et STEP du robot
    [Ass Act panneau solaire G.step, Assemblage pince gauche.step, Assembly barrilet.step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]
2024-06-12 Maj ressources des projets (deso arthur)
2024-06-12 Maj modifcation de recup et activation mermaid
2024-06-12 fix: actus n'a pas de children
2024-06-12 Ajout documentation servo moteurs
2024-06-12 Passage Chat GPT pour corriger les fautes
2024-06-12 ajout section barillet a la meca, ajout de lien
2024-06-12 ajout lien nema 17 dans la page barillet
2024-06-12 Passage de chat gpt sur V1 carte
2024-06-12 Passage de Chat gpt sur v2 carte
2024-06-12 Passage de chatgpt 4.0 sur v4
2024-06-12 derniers changements de la part de dylan
2024-06-12 Vraiment... dernier changement... ces messages me coutent du temps précieux de sommeils
2024-06-12 Juste pour la blague de rendu a 23h59
